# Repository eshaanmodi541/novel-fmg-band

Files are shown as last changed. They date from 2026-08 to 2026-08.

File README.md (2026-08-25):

# Novel FMG Band

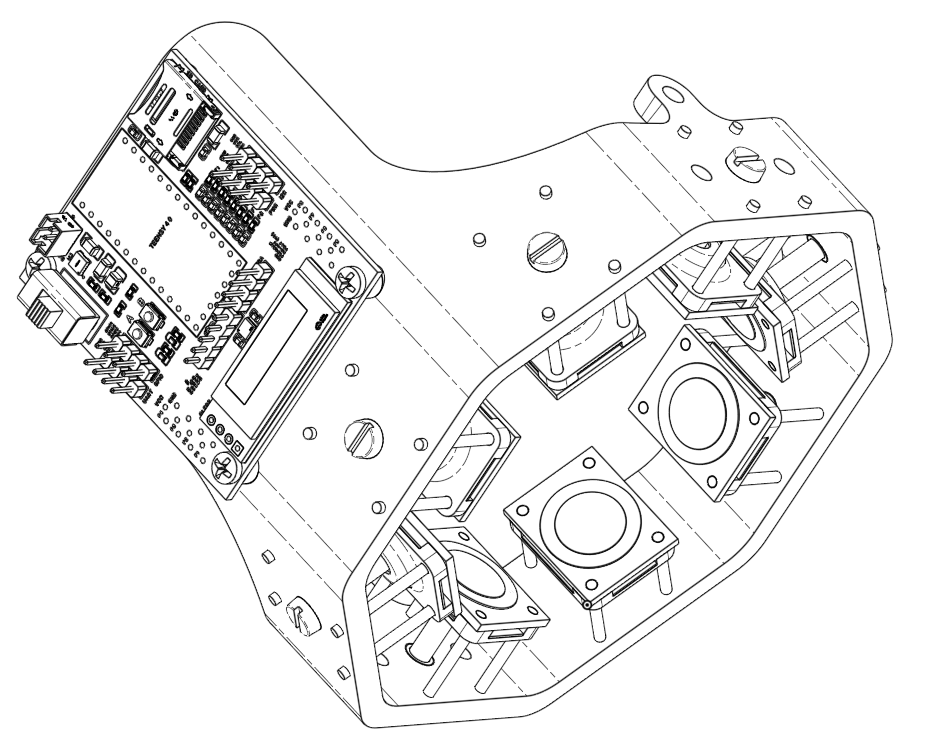
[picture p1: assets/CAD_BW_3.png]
CAD Assembly


A wearable Force Myography band that uses pressure measurements around the forearm to predict your hand movements! This technology can help in prosthetics, robotics control, and other HMI applications.

The core research investigates how sensor compression affects FMG accuracy and repeatability. This is almost never studied in current literature.

## Research

### Research questions

* How does sensor compression affect FMG gesture recognition accuracy?
* How does regulating compression between don/doff cycles affect the sensor's drift?

### Hypothesis

A moderate level of compression will produce the highest accuracy by providing consistent sensor contact without saturating the FMG signal.

The `/research` folder contains a one-page PDF explaining the research concept in more detail :)

## Hardware

### PCB

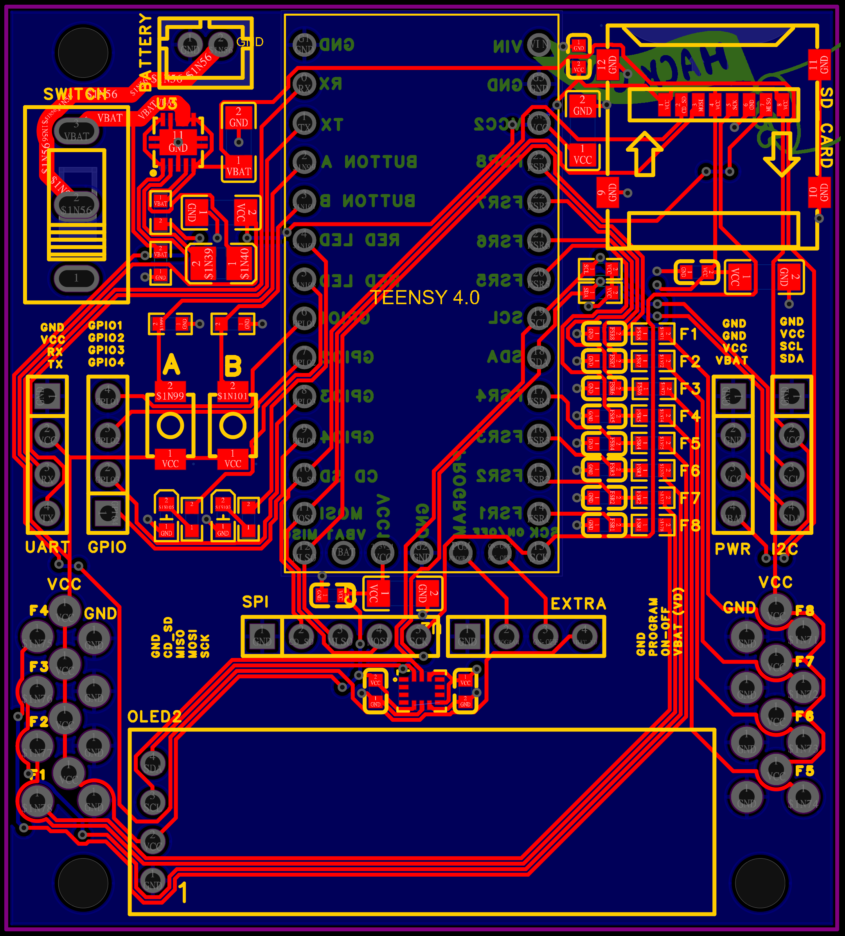
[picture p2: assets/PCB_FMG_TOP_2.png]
PCB

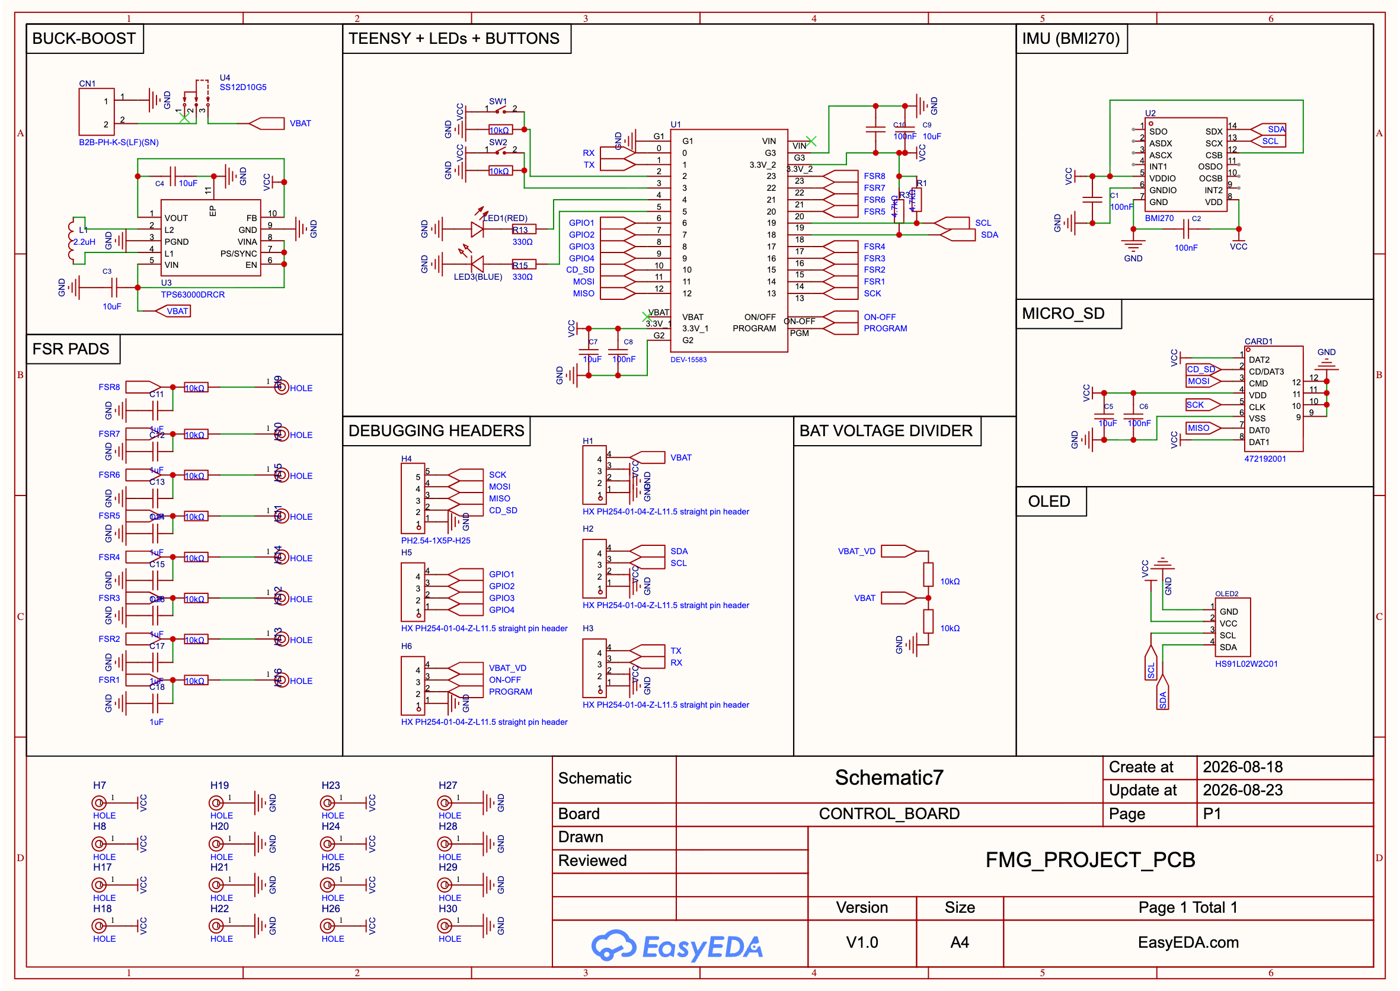
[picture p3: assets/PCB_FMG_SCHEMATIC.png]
Schematic


* **Teensy 4.0** — extremely fast microcontroller for real-time processing
* **8× Alpha FSRs** — pressure sensing around the forearm
* **BMI270 IMU** — tracks limb position
* **128×32 OLED** — displays system information
* **MicroSD card** — stores sensor data
* **TPS63000 buck-boost converter**
* **RC low-pass filters** on FSR inputs
* **Inverting op-amp stages** for FSR signal conditioning
* **3.7 V 2000 mAh LiPo** power
* **Breakout headers** for I²C, SPI, UART, GPIO, and power

### Mechanical Design

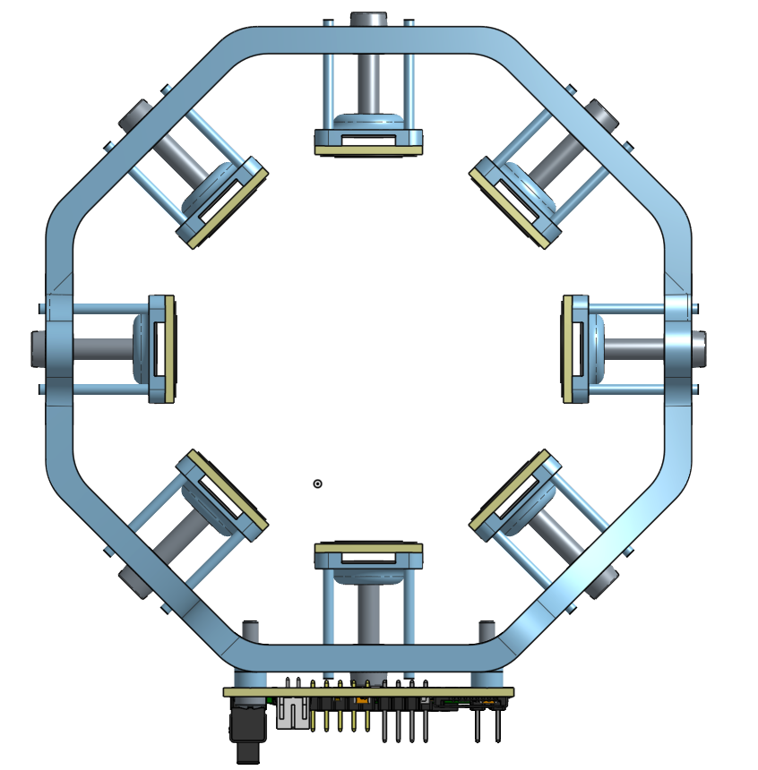
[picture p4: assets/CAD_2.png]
CAD DESIGN


The band uses a rigid structure with 8 individually adjustable screw-driven plungers that control the compression of each FSR individually. This allows me to study how the pressure of the band effects the accuracy.

Additionally when the FSRs are retracted, it is wide enough to easily slip on the band.

## Firmware

The band:

1. Collects FSR and IMU measurements extremely fast (600 MHz!).
2. Displays system information on the OLED screen (And what gestures the participants should perform).
3. Stores data on the MicroSD card (for training the model in the future!).
4. Uses collected data to train a neural network on my computer.
5. Loads the trained model onto the Teensy 4.0 for real-time gesture classification.

## Project Status

This project is currently still in the design phase.

CAD files, PCB designs, and the BOM are all in this repository for anyone who was inspired by this design or want to build it.

## Future Work

* Build a prosthetic hand controlled by the FMG band.
* Investigate additional issues with FMG.
* Make prosthetic control more affordable and reliable.

## Acknowledgments

Special thanks to Dr. Young and Dr. Stierotowicz for advising this project.

Special thanks to Hack Club for funding this and many other projects.

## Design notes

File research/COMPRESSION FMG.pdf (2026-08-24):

# Force Myography Compression Study Summary

Eshaan Modi | 9th grade | eshaanmodi541@gmail.com

Project Statement

Force myography’s main limitation is cross-session variance. In the papers I've found, cross-session sensor drift is handled with recalibration or domain adaptation rather than by controlling the mechanical variable directly. This project aims to fix this by correcting band compression – a variable that can affect gesture classification accuracy between don/doff cycles – in hardware.
When a band is re-donned it struggles from two mechanical confounds; namely band placement and compression. Finding the effect of band compression on sensor drift not only removes a potential source of classification accuracy loss, it also removes one of the two confounding signals thus allowing us to better quantify the components of sensor drift in FMG.

Approach

The modified band uses a pneumatic compression system: an inflatable sac constrained by a rigid outer ring, so inflation drives pressure inward onto the sensors against the skin. An embedded pressure sensor closes the feedback loop, letting the band hold a commanded pressure and return to a per-participant baseline recorded in the first session. Two sensor types are instrumented in parallel — force-sensitive resistors, the field standard, and barometric touch sensors, a newer approach — to test whether one is inherently less sensitive to compression variation. Placement is held constant independently of compression using anatomical landmarking and a keyed alignment feature on the band, so that drift in Stage 2 can be attributed to compression rather than repositioning. The experiment runs in two stages. First, a within-session pressure sweep measuring classification accuracy across pressure setpoints for both sensor types. Cho et al. found a rise-then-plateau across three discrete belt tensions; under continuous control I want to locate where that plateau begins and whether it differs between the two sensor types. A flat response would indicate placement dominates drift – still a useful negative result. Second, a cross-session comparison over multiple days with ten participants, running a conventional fixed strap against the dynamic band regulating each participant's session-one pressure. Training on the first session and testing on later ones isolates the effect of compression control on cross-session drift.

Current Status & Timeline

As of now, I am conducting deeper literature reviews and starting designing the project CAD and PCB files. I hope to have finished project design by mid-August, a revised prototype by October, preliminary data by December, and a completed project by February as this project will ultimately be presented at the Chester County Science Research Fair – a feeder into ISEF – in March. I hope a mentor can help me review my design, give me statistical guidance, sanity-check my protocol, and help me condense/analyze my findings.

Core Bibliography

Xiao, Zhen Gang, and Carlo Menon. "A review of force myography research and development." Sensors 19.20 (2019): 4557. Sherif, Omar, Mohamed Mahgoub Bassuoni, and Omar Mehrez. "A survey on the state of the art of force myography technique (FMG): analysis and assessment." Medical & Biological Engineering & Computing 62.5 (2024): 1313-1332.
Jiang, Xianta, et al. "Exploration of force myography and surface electromyography in hand gesture classification." Medical engineering & physics 41.1 (2017): 63-73.
Cho, Sung-Gwi, Hirochika Matsui, and Kengo Ohnishi. "Accuracy Comparison of FMG-based Hand-wrist Gesture Recognition with and without Compression." IEEE Access (2026).
Marquardt, Charlotte, et al. "Embedded barometric pressure sensor unit for force myography in exoskeletons." 2022 IEEE-RAS 21st International Conference on Humanoid Robots (Humanoids). IEEE, 2022.

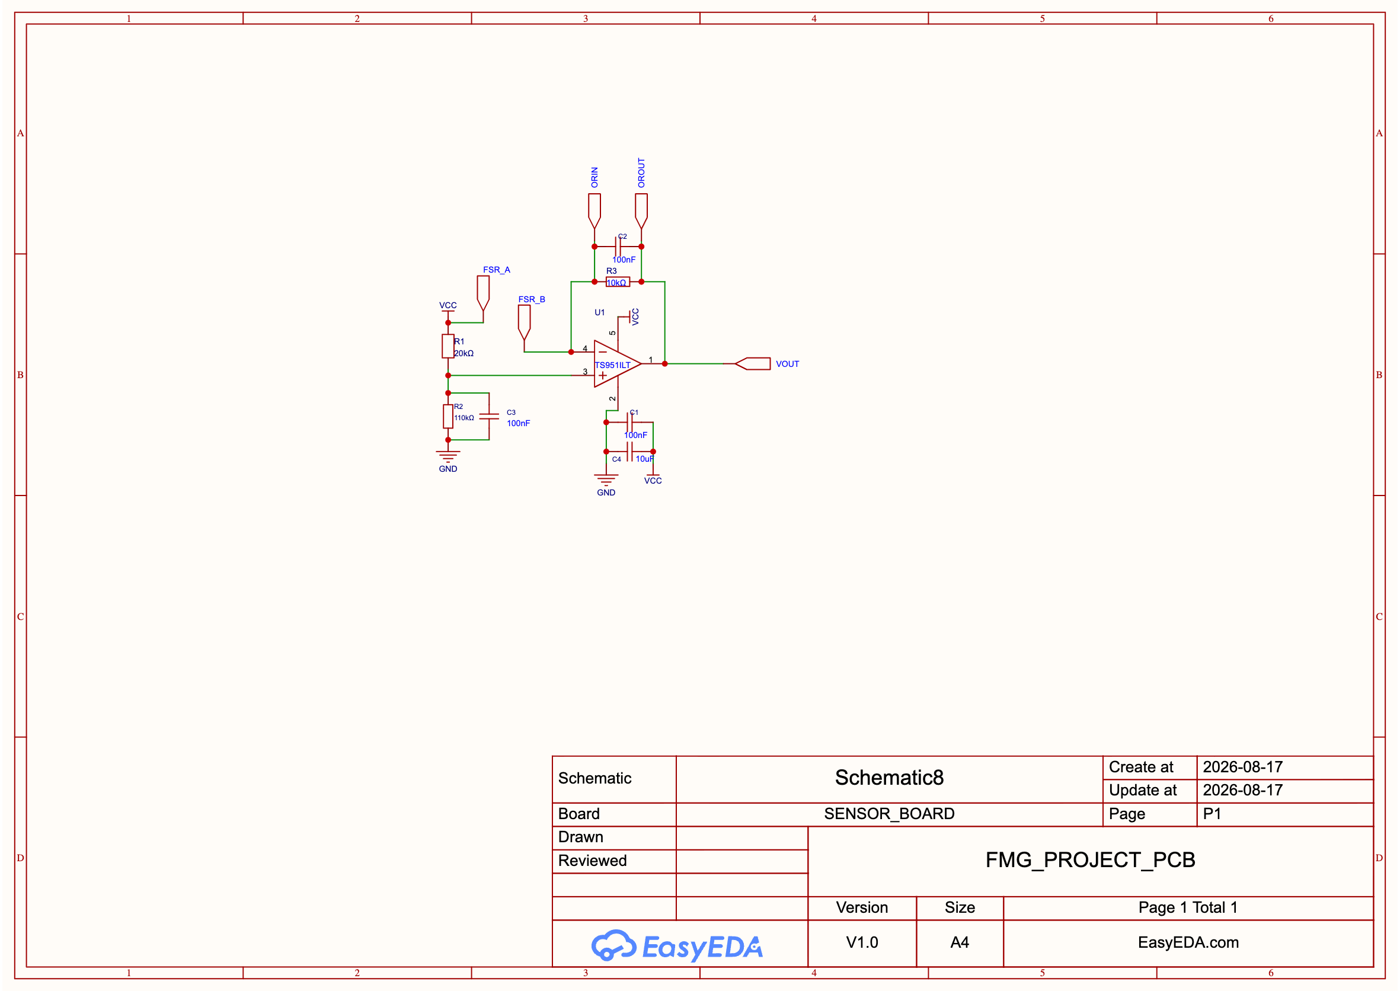
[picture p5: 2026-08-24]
assets/SENSOR_SCHEMATIC.png

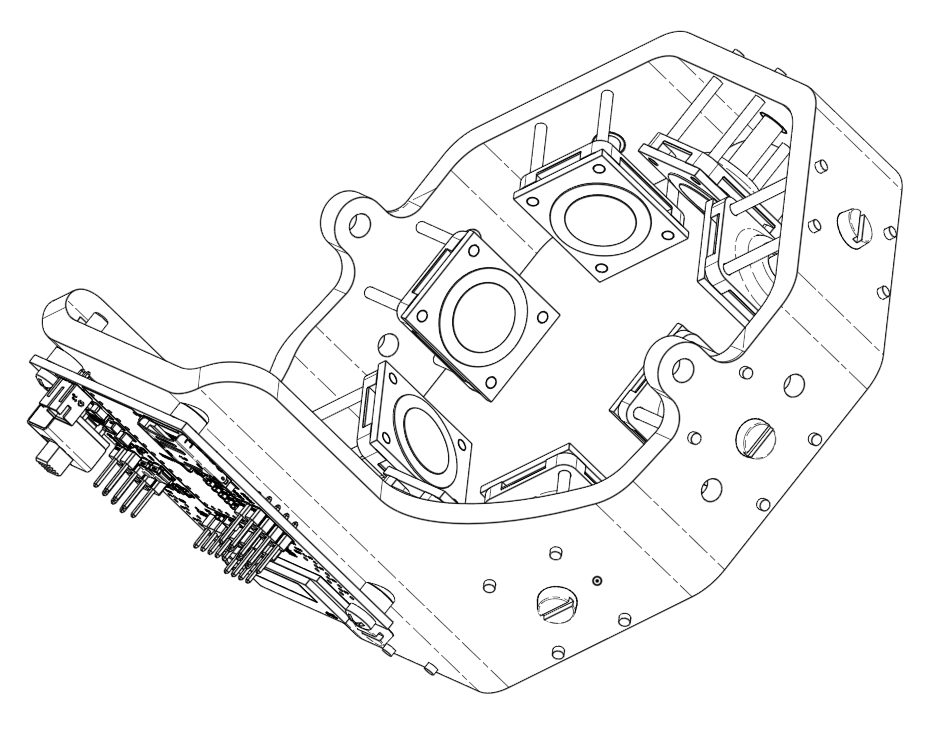
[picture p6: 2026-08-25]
assets/CAD_BW_2.png

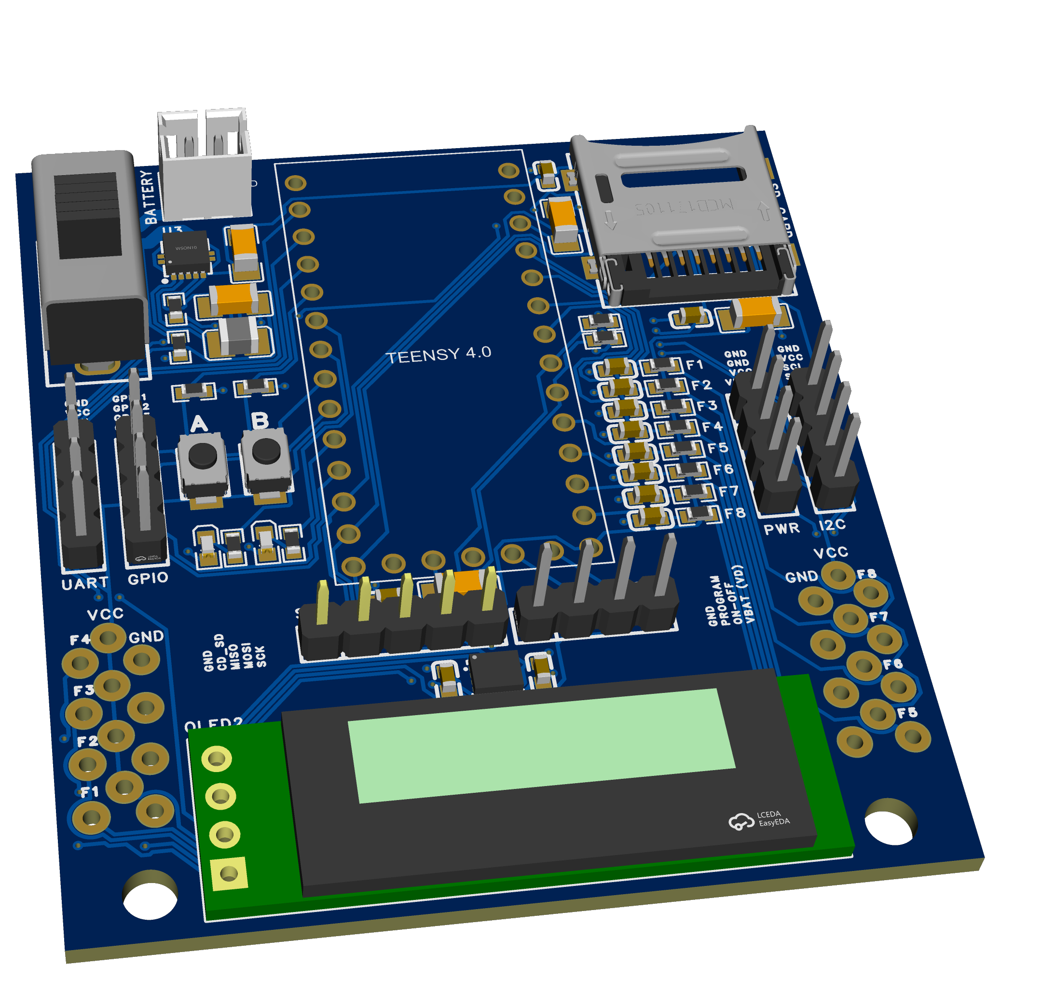
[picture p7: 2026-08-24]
assets/PCB_FMG_3D_3.png

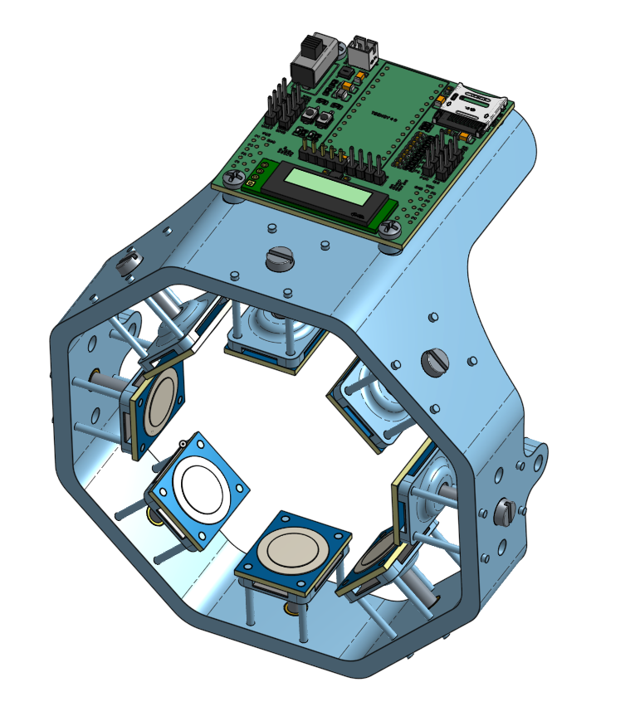
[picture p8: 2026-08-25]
assets/CAD_3.png

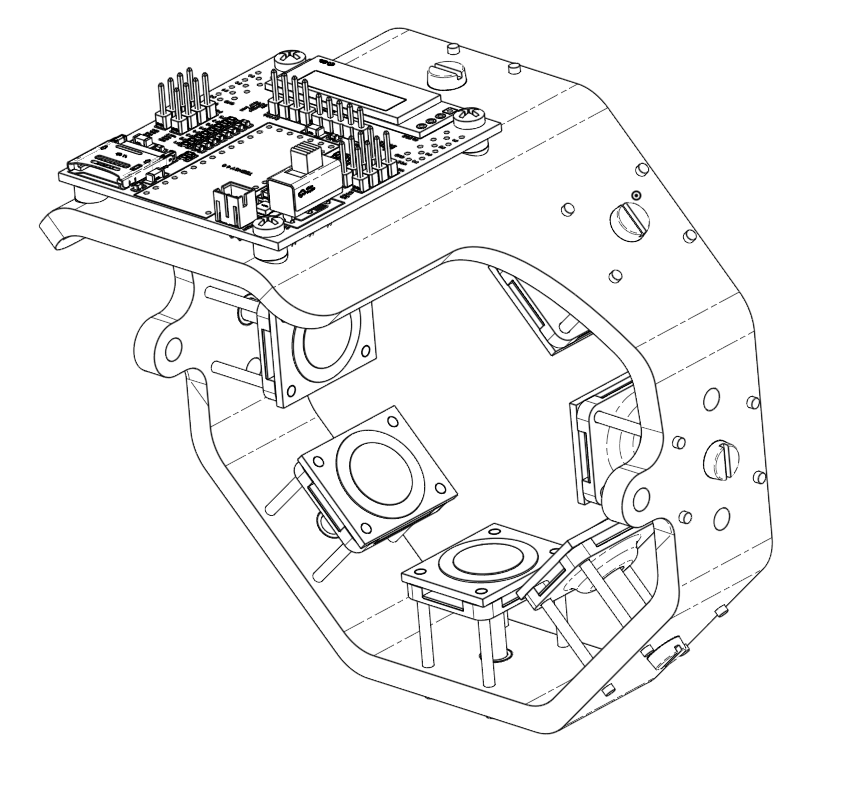
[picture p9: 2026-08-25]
assets/CAD_BW_4.png

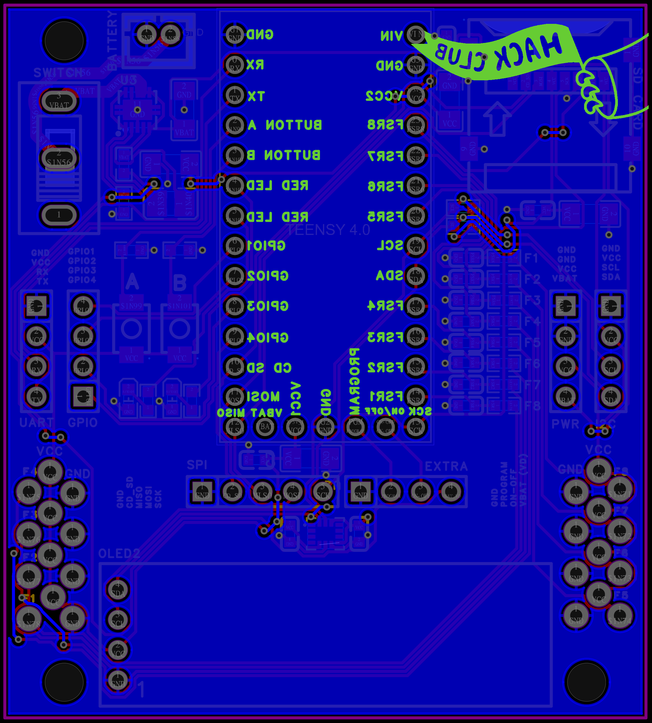
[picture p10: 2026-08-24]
assets/PCB_FMG_BOTTOM_2.png

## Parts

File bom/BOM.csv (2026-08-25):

Name | Description | Link | Unit Price | Amount | Total
SENSOR PCB | The small PCBs, that hold the FSR and have an Op-Amp for linearization. | (JLC PCB) N/A | N/A | 10 | 5.2
SENSOR PCB COMPONENTS | The individual components for the 10 boards I am buying them off of LCSC | LCSC BOM (IN GITHUB) | N/A | 10 | 15.6
CONTROL PCB + STENCIL | The base boards for the control board. minimum order size is 5. | (JLC_PCB) N/A | N/A | 5 | 9.16
CONTROL PCB COMPONENTS | The control PCB is too complicated to solder by hand so I am using JLC PCBA assembly service. only it will assemble two boards | LCSC BOM (IN GITHUB) | N/A | 1 | 38.32
LEAD SOLDER PASTE | I nead lead solder paste for the stencil. lead solder paste easier to work with. | https://www.amazon.com/Wonderway-Soldering-Electronics-CELLPHONE-Repairing/dp/B0BNKKRYK9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 | 9.99 | 1 | 9.99
ISOPROPYL ALCOHOL | very important since i am assembling boards by hand. this will clean up messes. I have some already so i dont need to buy it | https://www.wegmans.com/shop/product/326786-First-Aid-Antiseptic-91-Isopropyl-Alcohol | 2.29 | 1 | 0
FORCE SENSITIVE RESISTORS | these are the sensors we will have around the band which is the main sensing component of the project. | https://www.adafruit.com/product/166 | 3.95 | 10 | 39.5
2MM DOWELS/PINS | I found these on amazon and they look like a pretty good deal scince i wil lneed around 32 anyways | https://www.amazon.com/Stainless-Cylindrical-Fasteners-Furniture-Installation/dp/B0GFDHWZGM?s=industrial | 0.1 | 50 | 4.99
TEENSY 4.0 | Main processor since it has high quality ADC and sufficient processing speeds. Will buy from local microcenter to avoid shipping costs. | https://www.microcenter.com/product/699942/pjrccom-teensy-40-development-board | 23.99 | 1 | 23.99
BATTERY | simple LIPO battery that matches my dimentions | https://www.amazon.com/gp/product/B0GDQ7Q58F?s=bazaar | 8.49 | 1 | 8.49
THREADED INSERTS | M4 for the screw to go into precisely. | https://www.microcenter.com/product/675640/leo-sales-ltd-m4-threaded-insert-knurled-brass-nuts | 4.99 | 1 | 4.99
SCREWS ASSORTMENT | i got these again from micro center but i already have these so i shouldnt need to buy more | https://www.microcenter.com/product/623879/inland-bolt-set-330-pieces | 3.99 | 1 | 0
FEMALE HEADERS | I need these headers for the teensy since i need the teensy to be removable from the main board. | https://www.microcenter.com/product/427682/leo-sales-ltd-stackable-headers,-10-pin,-4-pack | 1.99 | 1 | 1.99
SOLDER FLUX | I dont have any solder flux right now so | https://www.amazon.com/Kaisiking-Soldering-Lead-Free-Solder-Electronics/dp/B0CZ6QWTK5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 | 7.89 | 1 | 7.89
KAPTON TAPE | This will help protect components while reflowing and keep stencil in place | https://www.amazon.com/VCHOMY-Sublimation-Polyimide-Temperature-Insulation/dp/B0C9PMHWGS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 | 4.99 | 1 | 4.99
PETG FILAMENT | all the parts should be PETG so they dont flex or snap | https://www.amazon.com/OVERTURE-Filament-Consumables-Dimensional-Accuracy/dp/B07PDV9RC8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 | 14.99 | 1 | 14.99
CONNECTORS | These are perfect they will connect 3 pins and can bridge the PCB and sensor boards | https://www.amazon.com/HSF-1-25mm-Connector-Terminal-Motherboard/dp/B0B3MN765F?s=industrial | 8.99 | 1 | 8.99
JLCPSCB + LCSC SHIPPING | This is just an estimate for the combined order shipping since it is difficult to tell without pying | N/A | N/A | N/A | 30
ADAFRUIT SHIPPING | shipping for adafruit | N/A | N/A | N/A | 5.89
TAX / TARRIFFS (ESTIMATED) | Chinese suppliers steep tarrifs and there is some tax at microcenter and amazon. | N/A | N/A | N/A | 15
 |  |  |  |  | 249.97

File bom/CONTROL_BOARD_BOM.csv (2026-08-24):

No. | Quantity | Comment | Designator | Footprint | Value | Manufacturer Part | Manufacturer | Supplier Part | Supplier
1 | 2 | HX 3x4x2-2P-2.5N-04 | A,B | SW-SMD_L4.0-W3.0-LS5.0 |  | HX 3x4x2-2P-2.5N-04 | hanxia(韩下) | C54407262 | LCSC
2 | 1 | B2B-PH-K-S(LF)(SN) | BATTERY | CONN-TH_B2B-PH-K-S |  | B2B-PH-K-S(LF)(SN) | JST | C131337 | LCSC
3 | 5 | 100nF | C1,C2,C6,C8,C10 | C0603 | 100nF | CL10B104KB8NNNC | SAMSUNG(三星) | C1591 | LCSC
4 | 5 | 10uF | C3,C4,C5,C7,C9 | C1206 | 10uF | CL31B106KBHNNNE | SAMSUNG(三星) | C89632 | LCSC
5 | 8 | 1uF | C11,C12,C13,C14,C15,C16,C17,C18 | C0603 | 1uF | CL10B105KA8NNNC | SAMSUNG(三星) | C29936 | LCSC
6 | 5 | HX PH254-01-04-Z-L11.5 straight pin header | EXTRA,GPIO,I2C,PWR,UART | HDR-TH_4P-HX-PH254-01-04-Z-L11.5 |  | HX PH254-01-04-Z-L11.5 straight pin header | hanxia(韩下) | C52016392 | LCSC
7 | 24 | HOLE | F1,F2,F3,F4,F5,F6,F7,F8,GND,GND,H7,H8,H18,H20,H21,H22,H24,H25,H26,H28,H29,H30,VCC,VCC | HOLEHOLE
8 | 1 | 2.2uH | L1 | L1008 | 2.2uH | APH252012C2R2MP01 | APV(爱普微) | C42455362 | LCSC
9 | 1 | YLED0603R | LED1(RED) | LED0603-FD |  | YLED0603R | YONGYUTAI(永裕泰) | C19171390 | LCSC
10 | 1 | YLED0603B | LED3(BLUE) | LED0603-FD |  | YLED0603B | YONGYUTAI(永裕泰) | C19171394 | LCSC
11 | 1 | HS91L02W2C01 | OLED2 | OLED-TH_L38.0-W12.0_HS91L02W2C01 |  | HS91L02W2C01 | HS(汉昇) | C5248081 | LCSC
12 | 2 | 4.7kΩ | R1,R3 | R0603 | 4.7kΩ | RC0603FR-074K7L | YAGEO(国巨) | C99782 | LCSC
13 | 12 | 10kΩ | R2,R4,R5,R6,R7,R8,R9,R10,R11,R12,R14,R16 | R0603 | 10kΩ | RC0603FR-0710KL | YAGEO(国巨) | C98220 | LCSC
14 | 2 | 330Ω | R13,R15 | R0603 | 330Ω | RC0603FR-07330RL | YAGEO(国巨) | C105881 | LCSC
15 | 1 | 472192001 | SD_CARD | TF-SMD_472192001 |  | 472192001 | MOLEX | C164170 | LCSC
16 | 1 | PH2.54-1X5P-H25 | SPI | HDR-TH_5P-P2.54-V-M-3 |  | PH2.54-1X5P-H25 | JXTCONN(聚兴泰) | C42431835 | LCSC
17 | 1 | SS12D10G5 | SWITCH | SW-TH_SHOU-HAN_SS12D10G4 |  | SS12D10G5 | SHOU HAN(首韩) | C7431054 | LCSC
18 | 1 | DEV-15583 | TEENSY 4.0 | MODULE_DEV-15583
19 | 1 | BMI270 | U2 | LGA-14_L3.0-W2.5-P0.50-BR |  | BMI270 | Bosch(博世) | C2836813 | LCSC
20 | 1 | TPS63000DRCR | U3 | SON-10_L3.1-W3.1-P0.50-TL-EP |  | TPS63000DRCR | TI(德州仪器) | C24966 | LCSC

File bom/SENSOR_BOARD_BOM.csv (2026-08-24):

No. | Quantity | Comment | Designator | Footprint | Value | Manufacturer Part | Manufacturer | Supplier Part | Supplier
1 | 3 | 100nF | C1,C2,C3 | C0603 | 100nF | CL10B104KB8NNNC | SAMSUNG(三星) | C1591 | LCSC
2 | 1 | 10uF | C4 | C1206 | 10uF | CL31B106KBHNNNE | SAMSUNG(三星) | C89632 | LCSC
3 | 1 | 20kΩ | R1 | R0805 | 20kΩ | FRC0805F2002TS | FOJAN(富捷) | C2907240 | LCSC
4 | 1 | 110kΩ | R2 | R0805 | 110kΩ | 0805W8F1103T5E | UNI-ROYAL(厚声) | C17422 | LCSC
5 | 1 | 10kΩ | R3 | R0603 | 10kΩ | RC0603FR-0710KL | YAGEO(国巨) | C98220 | LCSC
6 | 1 | TS951ILT | U1 | SOT-23-5_L3.0-W1.7-P0.95-LS2.8-BR |  | TS951ILT | ST(意法半导体) | C108177 | LCSC

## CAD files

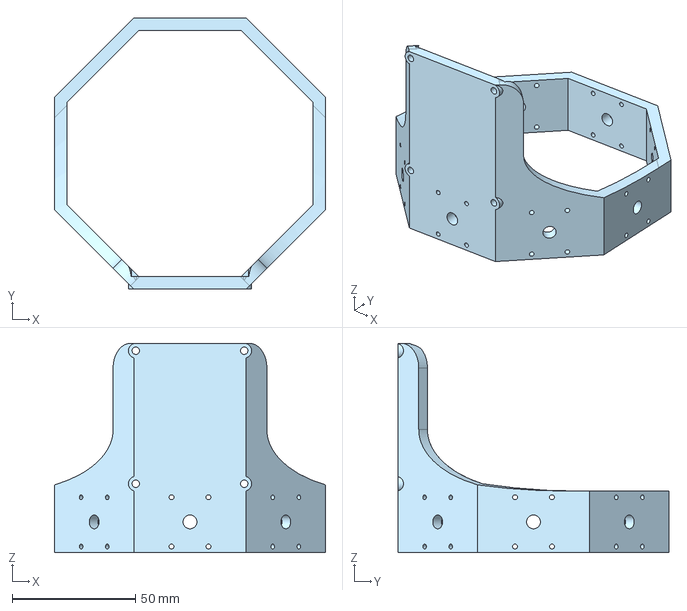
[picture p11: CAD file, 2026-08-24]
cad/MAIN_FRAME.step
110.0 x 110.0 x 85.0 mm

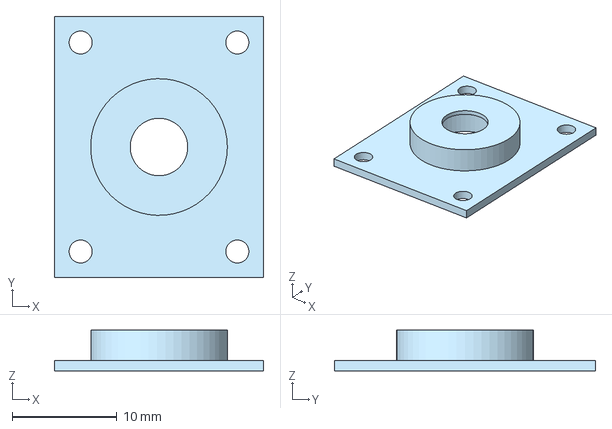
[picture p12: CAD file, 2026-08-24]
cad/SCREW_CARRIAGE.step
20.0 x 25.0 x 3.90 mm

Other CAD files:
cad/MAIN_FRAME.stl
cad/SCREW_CARRIAGE.stl

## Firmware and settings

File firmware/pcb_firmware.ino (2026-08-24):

#include <Wire.h>
#include "SparkFun_BMI270_Arduino_Library.h"

#include <Arduino.h>
#include "FS.h"
#include "SD.h"
#include "SPI.h"

#include <Wire.h>
#include <Adafruit_GFX.h>
#include <Adafruit_SSD1306.h>

#define SCREEN_WIDTH 128 
#define SCREEN_HEIGHT 32 

// NOTE: I havent really introduced RTOS tasks too much since the teensy is a monster
// in the future I will implement tasks in the same loop so i dont get any too long delays while writing to the OLED or SD
// I have left the OLED pretty useless for now I do not know what I am going to do with it
// this basicly just tests all the functions. main model training will happen on my laptop anyways...

int button_a_pin = 2;
int button_b_pin = 3;

int red_led = 4;
int blue_led = 5;

// SPI pins

int cd_sd = 10;
int mosi = 11;
int miso = 12;
int sck = 13;

File myFile;
int file_num = 0;
int row_counter = 0;

// I2C

int scl = 19;
int sda = 18;

// FSR

int fsr1_pin = 14;
int fsr1 = 0;
int fsr2_pin = 15;
int fsr2 = 0;
int fsr3_pin = 16;
int fsr3 = 0;
int fsr4_pin = 17;
int fsr4 = 0;

int fsr5_pin = 20;
int fsr5 = 0;
int fsr6_pin = 21;
int fsr6 = 0;
int fsr7_pin = 22;
int fsr7 = 0;
int fsr8_pin = 23;
int fsr8 = 0;

//OLED

Adafruit_SSD1306 display(SCREEN_WIDTH, SCREEN_HEIGHT, &Wire, -1);

// IMU

BMI270 imu;

void setup() {
  Serial.begin(9600);

  while (!Serial);
  Serial.println("Started Serial");

  SPI.begin();

  pinMode(button_a_pin, INPUT);
  pinMode(button_b_pin, INPUT);

  while(imu.beginI2C(BMI2_I2C_PRIM_ADDR) != BMI2_OK)
  {
    Serial.println("Error: BMI270 not connected, check wiring and I2C address!");
    delay(1000);
  }
  
  if (!SD.begin(cd_sd)) {
    Serial.println("SD INIT FAILED!");
    return;
  }

  if(!display.begin(SSD1306_SWITCHCAPVCC, 0x3C)) { 
    Serial.println(F("SSD1306 INNIT FAILED"));
    return;
  }

  display.clearDisplay();
  display.setTextSize(1);
  display.setTextColor(SSD1306_WHITE);

  display.setCursor(0, 0);
  display.println(F("OLED WORKS!"));

  display.display();
}

void loop() {

  if (myFile) {
    imu.getSensorData();

    float x = imu.data.gyroX;
    float y = imu.data.gyroY;
    float z = imu.data.gyroZ;

    fsr1 = analogRead(fsr1_pin);
    Serial.print(fsr1 + '\t');
    fsr2 = analogRead(fsr2_pin);
    Serial.print(fsr2 + '\t');
    fsr3 = analogRead(fsr3_pin);
    Serial.print(fsr3 + '\t');
    fsr4 = analogRead(fsr4_pin);
    Serial.print(fsr4 + '\t');
    fsr5 = analogRead(fsr5_pin);
    Serial.print(fsr5 + '\t');
    fsr6 = analogRead(fsr6_pin);
    Serial.print(fsr6 + '\t');
    fsr7 = analogRead(fsr7_pin);
    Serial.print(fsr7 + '\t');
    fsr8 = analogRead(fsr8_pin);
    Serial.print(fsr8 + '\t');

    unsigned long timeStamp = millis();

    myFile.print(timeStamp);
    myFile.print(",");
    myFile.print(fsr1);
    myFile.print(",");
    myFile.print(fsr2);
    myFile.print(",");
    myFile.print(fsr3);
    myFile.print(",");
    myFile.print(fsr4);
    myFile.print(",");
    myFile.print(fsr5);
    myFile.print(",");
    myFile.print(fsr6);
    myFile.print(",");
    myFile.print(fsr7);
    myFile.print(",");
    myFile.print(fsr8);
    myFile.print(",");
    myFile.print(x);
    myFile.print(",");
    myFile.print(y);
    myFile.print(",");
    myFile.println(z);

    row_counter += 1;

    if (row_counter % 100 == 0) {
      myFile.flush(); 
    }
  }

  if (digitalRead(button_a_pin) == HIGH) {
    String name = "DATA_" + String(file_num) + ".csv";

    myFile = SD.open(name.c_str(), FILE_WRITE);
    myFile.println("timestamp,fsr1,fsr2,fsr3,fsr4,fsr5,fsr6,fsr7,fsr8,imux,imuy,imuz");
    Serial.println("CREATED NEW FILE: " + name);
    myFile.flush();

    file_num++;
    delay(500);
  }

}

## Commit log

2026-08-24 created base repo
    [CONTROL_BOARD_BOM.csv, CONTROL_BOARD_PnP.xlsx, FULL_FMG_BOM.csv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]
2026-08-24 renamed BOM
    [BOM.csv]
2026-08-25 added CAD images and rewrote readme
2026-08-25 updated BOM
    [BOM.csv]
